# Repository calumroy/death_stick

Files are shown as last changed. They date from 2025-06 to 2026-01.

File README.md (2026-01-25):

# Death Stick

A fun death stick.

## Button Controls

Three speed buttons (active LOW, active while held):
- **SLOW** (GP2): 20A - Low power
- **MEDIUM** (GP3): 40A - Normal cruising  
- **FAST** (GP4): 70A - Full power (ramps up over 1 second)

Release all buttons to stop.

**Emergency Stop:** Hold all 3 buttons for 2 seconds. Current cuts immediately when all buttons are pressed.

**Exit Emergency Stop:** Press and hold each button in sequence (SLOW → MEDIUM → FAST), holding each for 500ms. If multiple buttons are pressed simultaneously, the sequence resets.

## Software 

The controller is an [ESP32-S3-LCD-1.47B](https://www.waveshare.com/wiki/ESP32-S3-LCD-1.47B) board.

Building and flashing the software is done using the containerized ESP-IDF build (Podman).

### Containerized ESP-IDF build (Podman)

Build and flash ESP-IDF projects in a container with access to `/dev/ttyACM0`.

Prereqs: Podman installed; user can access serial devices (often group `dialout`).

1) Initialize ESP-IDF submodule

```bash
git submodule update --init --recursive software/esp_idf
```

2) Build image

```bash
bash scripts/podman-build.sh
```

3) Run container (maps repo, caches tools, exposes `/dev/ttyACM0`)

Check that once the device is plugged in, the device is recognized by the host and is on the `/dev/ttyACM0` path.
If it comes up as something else, you can try to run the container with a different device:

```bash
bash scripts/podman-run.sh
```

Use another device:

```bash
TTY_DEVICE=/dev/ttyUSB1 bash scripts/podman-run.sh
```

Inside the container (ESP-IDF is already exported by entrypoint):

```bash
idf.py --version
idf.py set-target esp32s3
cd ./software/src/stick_controller
idf.py build
idf.py -p /dev/ttyACM0 flash monitor
```c
Quit the serial monitor by typing Ctrl-]
--- Quit: Ctrl+] | Menu: Ctrl+T | Help: Ctrl+T followed by Ctrl+H

Reattach to a running container:

```bash
bash scripts/podman-exec.sh bash
```

Troubleshooting:
- If serial permissions fail, ensure the host user is in `dialout` and the device exists. You can try `TTY_DEVICE=/dev/ttyACM0`.
- Tools cache persists in `.espressif`. Delete it to force re-install.

- If you power cycle the ESP or disconnct the USB and reconnct the podman container will need to be restarted otherwise it won't get permission to use the device serial port anymore.

## Flipsky Uart settings

App Settings → UART
    Baud rate: 115200
    UART Mode: UART
App to Use: UART

We use Uart0 to communicate from the ESP32 to the Flipsky ESC.

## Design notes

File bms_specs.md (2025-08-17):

## BMS Specifications

From here: 
https://flipsky.net/collections/bms/products/bms-8s-14s-lifepo4-li-ion

Charging current: <60A
Discharge current: < 150A
Internal resistance: ≤15mΩ
Charging voltage: The number of Li-ion battery in series connection X 4.2V
Wiring: Different Port

Detection voltage: 4.25±0.025V
Detection delay: 1000±500MS
Release voltage: 4.15±0.05V

Detection voltage: 2.75±0.1V
Detection delay: 1000±500MS
Release voltage: 3.0±0.1V

Detection voltage: 4.15±0.025V
Detection delay: 100±50MS
Balance current: 42±5MA

Detection voltage: 50±15MV
Detection delay: 1000±500MS
Current protection: 300±50A 450±50A 600±60A

Trigger condition: external short circuit
Detection delay: 300us
Release condition: disconnect the load

Charge and discharge over-temperature protection: 55℃
Charge and discharge high temperature release temperature: 75℃
Release condition: During normal working temperature

Working power consumption: <35UA
Over-discharge power consumption (Sleeping State): <10UA
Operating temperature range: -30°~+80°C

Overcharge protection
Over discharge protection
Over current protection
Balanced protection
Temperature control protection
Applicable for 8-14S battery

Size: 121*50*12.8mm
Net weight: 244g
Weight: 331.5g

1x PCBA board
1x HY2.0 single head 15P line

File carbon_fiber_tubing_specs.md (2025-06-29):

# Carbon Fiber Tubing Specs

Form here
https://enhancedcomposites.com.au/product/carbon-fibre-roll-wrap-tube-60mm-x-56mm-x-2360/

## Specs

Carbon Fibre Roll Wrap Tube – 60 x 56 x 2360 mm

$517.00 incl. GST

Length: 2360 mm
Outside Diameter (OD): 60 mm
Inside Diameter (ID): 56 mm
Wall Thickness: 2 mm

Colour: 2×2 twill carbon fibre weave finish
Type: Roll wrap 100% carbon fibre
Appearance: Glossy
Resin Matrix: Epoxy

## Description

Enhanced Composites carbon fibre roll wrap tube uses high strength unidirectional carbon fibre running length-ways down the tube for stiffness and at 90° around the tube to provide hoop strength and resilience to crush, burst and torsional loads. In addition to this high strength uni core, our tubes are finished with a classic final layer of 2×2 twill weave carbon fibre and UV-stable clear high-gloss finish. The end result is a carbon fibre tube ideally suited for use in applications where it will be seen.

The tube has an outer diameter (OD) of 60 mm and an inner diameter (ID) of 56 mm.
How to Cut and Shape

They can be cut with a fine band saw, hacksaw, or dremel tool. Enhanced Composites roll wrap carbon fibre tubes are manufactured using an epoxy matrix; therefore they will easily bond with other epoxy resins.
Typical Uses

Roll-wrapped tubes are better for applications where the tube may be subject to a variety of forces including bend, twist and crush. These light 10 mm tubes are suitable for demanding engineering applications including scale aircraft, gliders, helicopter U.A.V.’s, lightweight frames or structures, tubular vessels, poles, column supports or any construction that requires strength, rigidity and lightness yet appearance is also important. They are equally suited to other precision applications like robotics and automation.

Tubes made with epoxy resin systems have virtually zero water absorption, making them suitable for marine-based use than lower-quality tubing made with vinylester or polyester resin systems.

Discounts are available for larger quantities

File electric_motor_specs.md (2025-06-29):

# Electric Motor Specifications

options

## Flipsky 65150 Motor 160KV 3000W IP68 BLDC Motor / ESC 2-in-1 Combo For Surfing Boat Underwater Thruster |Hydro | Efoil 
In built ESC (motor controller)
https://flipsky.net/collections/waterproof-motor/products/65150-motor-160kv-3000w-ip68-bldc-motor-esc-2-in-1-combo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

Flipsky 65150 Motor 160KV 3000W IP68 BLDC Motor / ESC 2-in-1 Combo For Surfing Boat Underwater Thruster |Hydro | Efoil 

    Size: ∅ 65*150mm
    KV:160KV
    Voltage range: 4-13S
    Rated current: 30A;Maximum current:70A
    Insulation current:AC500v/1ma/3s
    Rated power:1500W;Maximum power:3000W
    Rated torque:2.3N.m;Maximum torque 4.5N.m
    Internal structure:12N/10p
    ESC drive mode:PPM
    Communication port: USB
    ESC driver firmware:5.2 vesc tool 3.00
    ESC support mode: BLDC/FOC
    Shaft specifications ∅ 12-0.005/-0.01
    Power cable: 2*12AWG(∅ 4.5mm*140)
    Power plug: XT90 male
    Weight:2.0kg

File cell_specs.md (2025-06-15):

## Specification for NMC cell
https://www.alibaba.com/product-detail/46160-NMC-Cylindrical-Cell-Rechargeable-3_1600482704719.html

Battery type
3.7V NCM Lithium Cylindrical Battery
Capacity
Max. 32Ah
Min. 31Ah
Nominal Voltage
3.7V
Max Charge Voltage
4.2V
Discharge Cut-off Voltage
2.7V
Internal Resistance
≤1mΩ
Weight
680±10g
Size
46*167(mm)
Cycle Life
>1500 times (80% of initial capacity at 2C rate, IEC Standard)
Charging Current
.Standard Charging: 62A
.Max. Charging: 93A
Disharging Current
.Max discharge current : 124A(4C)
.Max. Peak Discharging : 310A(10C)
Storage Temperature
· ≤1month: -10–45℃
· ≤3month: 0–30℃
· ≤6month: 20±5℃
Monthly self-discharge rate
≤2.5% month
Charge Temperature
0°C ~ 45°C
Discharge Temperature
-20°C ~ 60°C
Terminal
M6 Studs
Charge Mode

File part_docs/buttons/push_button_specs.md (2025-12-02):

This button is a momentary button switch(Jog switch). It means that the power is only applied when the button is pressed.Once the hand is released, the button switch is automatically reset and the power is off.
The key stroke of the product is ultra-short, the volume is ultra-thin, and the rated current is 1A

Manufacture VaneAims

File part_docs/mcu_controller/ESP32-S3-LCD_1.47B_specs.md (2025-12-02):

## ESP32-S3-LCD-1.47B

See the Waveshare wiki for details: [ESP32-S3-LCD-1.47B](https://www.waveshare.com/wiki/ESP32-S3-LCD-1.47B)

**Important:** Do not remove the screen when soldering the header pins. Tilt the iron and solder directly.

### Introduction

ESP32-S3-LCD-1.47B is a microcontroller development board with 2.4GHz Wi‑Fi and Bluetooth BLE 5. It integrates large‑capacity Flash and PSRAM and includes a 1.47" LCD capable of smoothly running GUI frameworks such as LVGL. With rich peripheral interfaces, it suits rapid HMI development and other ESP32‑S3 applications.

### Features

- Equipped with high‑performance Xtensa 32‑bit LX7 dual‑core processor, up to 240MHz
- 2.4GHz Wi‑Fi (802.11 b/g/n) and Bluetooth 5 (BLE), onboard antenna
- Built‑in 512KB SRAM, 384KB ROM, 8MB PSRAM, and 16MB Flash
- Onboard 1.47" LCD, 172×320 resolution, 262K color
- Adapts most GPIOs; integrates full‑speed USB serial port
- Onboard QMI8658 6‑axis IMU (3‑axis accelerometer + 3‑axis gyroscope)
- Onboard RGB light bead with acrylic light guide
- Onboard TF card slot for external storage
- Battery charging management module (battery connector at pin header area)
- Flexible clock and multiple power modes for low‑power scenarios

### Onboard Resources

Board overview

1. ESP32‑S3R8 — dual‑core processor, up to 240MHz  
2. 16MB Flash  
3. RGB light bead — works with onboard acrylic for lighting effects  
4. ME6217C33M5G — LDO regulator, up to 800mA output  
5. QMI8658 — six‑axis gyro accelerometer  
6. Charging management circuit  
7. Patch ceramic antenna  
8. Battery header — 3.7V Li‑ion/Li‑Po, supports charge and discharge  
9. TF card slot  
10. RESET button  
11. BOOT button  
12. Type‑C interface — power, USB communication, firmware download

### Pinouts

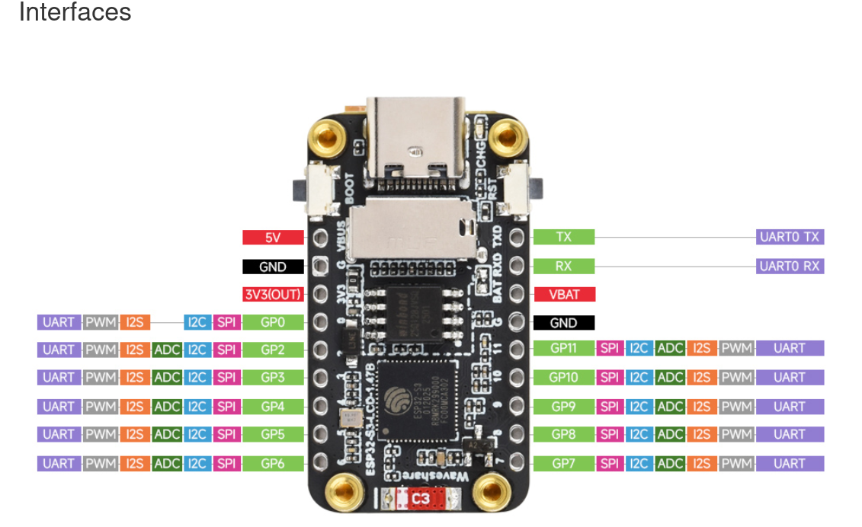
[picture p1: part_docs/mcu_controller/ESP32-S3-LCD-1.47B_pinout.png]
Pinouts


**Left-Side Pins**  

| Pin Label | Functions |
|---|---|
| **5V** | 5V Power Input |
| **GND** | Ground |
| **3V3 (OUT)** | 3.3V Output |
| **GP0** | UART, PWM, I2S, I2C, SPI |
| **GP2** | UART, PWM, I2S, ADC, I2C, SPI |
| **GP3** | UART, PWM, I2S, ADC, I2C, SPI |
| **GP4** | UART, PWM, I2S, ADC, I2C, SPI |
| **GP5** | UART, PWM, I2S, ADC, I2C, SPI |
| **GP6** | UART, PWM, I2S, ADC, I2C, SPI |

**Right-Side Pins**  

| Pin Label | Functions |
|---|---|
| **TX** | UART0 TX |
| **RX** | UART0 RX |
| **VBAT** | Battery Input |
| **GND** | Ground |
| **GP11** | SPI, I2C, ADC, I2S, PWM, UART |
| **GP10** | SPI, I2C, ADC, I2S, PWM, UART |
| **GP9**  | SPI, I2C, ADC, I2S, PWM, UART |
| **GP8**  | SPI, I2C, ADC, I2S, PWM, UART |
| **GP7**  | SPI, I2C, ADC, I2S, PWM, UART |

LCD (ST7789 controller)

| Signal | ESP32‑S3 GPIO |
|---|---|
| MOSI | GPIO45 |
| SCLK | GPIO40 |
| LCD_CS | GPIO42 |
| LCD_DC | GPIO41 |
| LCD_RST | GPIO39 |
| LCD_BL | GPIO46 |

RGB light bead

| Signal | ESP32‑S3 GPIO |
|---|---|
| RGB_Control | GPIO38 |

TF Card

| Signal | ESP32‑S3 GPIO |
|---|---|
| SD_CMD | GPIO15 |
| SD_SCK | GPIO14 |
| SD_D0  | GPIO16 |
| SD_D1  | GPIO18 |
| SD_D2  | GPIO17 |
| SD_D3  | GPIO21 |

### Specifications

| Item | Parameter |
|---|---|
| Interface | USB Type‑C |
| Controller chip | ESP32‑S3 |
| LCD type | TFT |
| LCD controller chip | ST7789 (display) |
| Onboard devices | RGB light bead |
| | TF card slot |
| | QMI8658 6‑axis IMU |
| | Charging management IC |

**Important:** Do not remove the screen when soldering the header pins. Tilt the iron and solder directly.

### Usage Instructions

ESP32‑S3‑LCD‑1.47B currently provides two development tools/frameworks: Arduino IDE and ESP‑IDF. Choose based on your project needs and personal preference.

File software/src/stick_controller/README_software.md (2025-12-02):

## Death Stick Controller Software

ESP32-S3-LCD-1.47B based motor controller with VESC UART communication.

### Features

- **VESC UART Communication**: Communicates with Flipsky VESC motor controller at 115200 baud
- **Three Speed Levels**: SLOW, MEDIUM, FAST buttons to control motor current
- **LCD Telemetry Display**: Shows voltage, current, RPM, temperature, and fault status
- **Emergency Stop**: Long-press any button to immediately stop the motor

### Hardware Connections

#### VESC UART (UART0)
| ESP32 Pin | VESC Wire | Function |
|---|---|---|
| TX (GPIO43) | Yellow | VESC RX |
| RX (GPIO44) | White | VESC TX |
| 5V | Red | Power |
| GND | Black | Ground |

#### Speed Control Buttons (Active LOW with internal pull-ups)
| ESP32 Pin | Button | Function |
|---|---|---|
| GP2 | SW1 | SLOW speed |
| GP3 | SW2 | MEDIUM speed |
| GP4 | SW3 | FAST speed |
| GND | All switches | Common ground |

### Current Settings

This project shows a background image behind the two toggle images using an LVGL image compiled into the firmware as a C array.

What’s in the code
- `main/images/screenshot1.c` defines a `const lv_img_dsc_t screenshot1` with RGB565 pixels (stored in flash).
- `main/main.c` creates an LVGL image object and sets that descriptor as the source:
  - `lv_img_set_src(bg_img_obj, &screenshot1);`
  - It’s aligned top-left, under the two foreground images.
- Build is wired in `main/CMakeLists.txt` by listing `images/screenshot1.c` among the component sources.

Replace the background (recommended)
1) Prepare your image
- Target screen size: 172x320 (portrait) for the ST7789 panel.
- Use the LVGL Image Converter: [LVGL Image Converter](https://lvgl.io/tools/imageconverter)
- Settings:
  - Color format: RGB565
  - Output: C array
  - Dithering/Compression: Off
  - Variable name: `screenshot1` (to avoid any code changes)

Inside the ESP-IDF container:

```bash
cd /workspace/software/src/stick_controller
idf.py fullclean
idf.py build
idf.py -p ${TTY_DEVICE:-/dev/ttyACM0} flash monitor
```

### Usage

1. **Power on** - The LCD will show "VESC: Connecting..." until communication is established
2. **Select speed** - Press GP2 (SLOW), GP3 (MEDIUM), or GP4 (FAST) to set motor current
3. **Toggle off** - Press the same button again to stop the motor
4. **Emergency stop** - Long-press any button to immediately stop

### LCD Display Information

- **SPEED**: Current speed setting (OFF/SLOW/MEDIUM/FAST)
- **VOLT**: Battery voltage from VESC
- **CMD**: Commanded current (what you requested)
- **MOTOR**: Actual motor current (what's flowing)
- **RPM**: Motor RPM
- **TEMP**: MOSFET temperature
- **VESC**: Connection status or fault code

### File Structure

```
main/
├── main.c                    # Main application
├── Button_Driver/
│   ├── Button_Driver.c/h     # Internal BOOT button
│   ├── Speed_Buttons.c/h     # External speed buttons (GP2,GP3,GP4)
│   └── multi_button.c/h      # Button debounce library
├── VESC_Driver/
│   └── vesc_uart.c/h         # VESC UART communication driver
├── LCD_Driver/
│   └── ST7789.c/h            # LCD driver
├── LVGL_Driver/
│   └── LVGL_Driver.c/h       # LVGL graphics driver
└── images/
    └── *.c                   # Image assets
```

### VESC Configuration

The VESC must be configured for UART communication:

1. Open VESC Tool
2. Go to **App Settings → UART**
3. Set **Baud rate**: 115200
4. Set **UART Mode**: UART
5. Go to **App Settings → General**
6. Set **App to Use**: UART

### Troubleshooting

- **"VESC: No Connection"** - Check UART wiring (TX→RX crossover), verify VESC is powered and configured for UART mode
- **Motor doesn't respond** - Verify current limits in VESC Tool, check fault codes on display
- **Buttons not working** - Verify GP2/GP3/GP4 are connected to buttons that pull to GND when pressed
- **Display garbled** - May need to clean build: `idf.py fullclean && idf.py build`

### Safety Notes

⚠️ **CAUTION**: This controls a potentially dangerous motor. Always:
- Test with motor disconnected first
- Start with low current values
- Have emergency stop ready (long-press any button)
- Never leave unattended while powered

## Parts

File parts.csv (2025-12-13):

Part | Model | Vendor Part no | Description | Quantity Required | Quantity Ordered | Cost $(of ordered quantity) | Cost $(of required quantity) | Currency | Vendor Supplier | Order Status | date ordered | URL Link
Threaded Rod |  | 175-7001 | Zinc Plated Mild Steel Threaded Rod M6 20mm | 11 | 1 bag of 50 | 26.40 | 5.80 | AUD | RS Components | Ordered | 10/06/25 | https://au.rs-online.com/web/p/threaded-rods/1757001
spring washer |  | 175-7002 | Zinc Plated Mild Steel Spring Washer M6 | 11 | 1 bag of 100 | 7.22 | 0.79 | RS Components | Ordered | 10/06/25 |  | https://au.rs-online.com/web/p/washers/2310693
Cable Gland | 50.112/EMV/R | 2291-50.112/EMV/R-ND | CABLE GLND 5-13MM 1/2 NPT BRASS | 6 | 6 | 35.88 | 35.88 | USD | DigiKey | Ordered |  | https://www.digikey.com.au/en/products/detail/jacob-gmbh/50-112-EMV-R/11674819
Cable Gland | NGM Series | 8829947 | HellermannTyton NGM Series Grey Nylon Cable Gland M12 Thread 3-6.5mm IP68 10 | 1 | 10 | 15.10 | 15.10 | AUD | RS Components | Ordered | 14/07/25 | https://au.rs-online.com/web/p/cable-glands/8829947
Heatset Insert | 4256 | 1528-4256-ND | BRASS HEATSET INSRT M3X3M 1=50PC | 50 | 1 bag of 50 | 5.95 | 5.95 | USD | DigiKey | Ordered |  | https://www.digikey.com.au/en/products/detail/adafruit-industries-llc/4256/10244655
PETG Filament | PETG175N1 | 4370-PETG175N1-ND | ESUN PETG (1.75MM 1000G)NATURE | 1 | 1 | 21.09 | 21.09 | USD | DigiKey | Ordered |  | https://www.digikey.com.au/en/products/detail/esun/PETG175N1/16734901
ABS+ Filament | ABS+175B1 | 4370-ABS+175B1-ND | ESUN ABS (1.75MM 1000G)BLACK | 1 | 1 | 21.09 | 21.09 | USD | DigiKey | Ordered |  | https://www.digikey.com.au/en/products/detail/esun/ABS-175B1/16583788
Wireless Remote VX3 |  |  | Flipsky 2.4G Wireless Module Waterproof Remote VX3 Pro controller for Efoil/ESurf/ESK8 | 1 | 1 | 110.00 | 110.00 | USD | Flipsky | Ordered | 06/07/25 | https://flipsky.net/products/flipsky-vx3-waterproof-remote-controller
Flipsky BMS |  |  | Flipsky BMS 8S-14S LiFePO4/Li-ion 24V/36V/48V Battery Pack Protection 150A for ESK8/Electric Scooter | 1 | 1 | 45.00 | 45.00 | USD | Flipsky | Ordered | 06/07/25 | https://flipsky.net/collections/bms/products/bms-8s-14s-lifepo4-li-ion
Flipsky 65150 Motor Combo | FS078 |  | Flipsky 65150 Motor 160KV 3000W IP68 BLDC Motor / ESC 2-in-1 Combo w/ prop PPM&UART 160KV | 1 | 1 | 345.60 | 345.60 | USD | Flipsky | Ordered | 06/07/25 | https://flipsky.net/collections/waterproof-motor/products/65150-motor-160kv-3000w-ip68-bldc-motor-esc-2-in-1-combo
O-Ring | RS PRO | 196-4904 | RS PRO Nitrile Rubber O-Ring 40mm Bore 44mm Outer Diameter |  | 1 bag of 50 | 20.32 | 0.40 | AUD | RS Components |  |  | https://au.rs-online.com/web/p/gaskets-o-rings/1964904
Polycarbonate Sheet | Aliexpress |  | 4mm Clear Polycarbonate Sheet 200x300mm |  | 1 | 25.79 | 25.79 | AUD |  | Ordered |  | https://www.aliexpress.com/item/1005008523118509.html
Push Button Switch | Aliexpress |  | Ultra Short Push Button Switch Waterproof 16mm 3-6v Blue LED Black Shell Momentary Self-reset | 3 | 6 | 38.28 | 19.14 | AUD | AliExpress | Ordered |  | https://www.aliexpress.com/item/1005005810452249.html
Self-Adhesive Sponge | Aliexpress |  | Self-Adhesive Sponge |  |  | 35.66 | 35.66 | CNY | AliExpress | Ordered |  | https://www.aliexpress.com/item/1005006761972394.html
Electrical Insulating Tape | Aliexpress |  | Electrical Insulating Tape Heat Resistant |  |  | 38.39 | 38.39 | CNY | AliExpress | Ordered |  | https://www.aliexpress.com/item/1005009717589369.html
O-Ring | RS PRO | 196-5062 | RS PRO Nitrile Rubber O-Ring 58mm Bore 64mm Outer Diameter |  | 1 | 16.89 | 16.89 | AUD | RS Components | Ordered | 31/08/25 | https://au.rs-online.com/web/p/gaskets-o-rings/1965062
ESP32-S3 Dev Board | Waveshare |  | Waveshare ESP32-S3 1.47-inch LCD Screen Dev Board WiFi Bluetooth RGB 172x320 Dual Core |  | 1 | 145.05 | 145.05 | CNY | AliExpress | Ordered | 13/09/25 | https://www.aliexpress.com/item/1005009453213461.html
DC-DC Buck Module | Mini Buck 2A |  | DC-DC Buck Module 60V/48V/36V/24V to 3.3V Output Car Power Converter 2A |  | 1 | 33.45 | 33.45 | CNY | AliExpress | Ordered | 13/09/25 | https://www.aliexpress.com/item/1005008564266624.html
Cable |  | W4216A | CABLE HIGH CURR. 90A RED | 2.0 | 2 | 16.4 | 16.4 | AUD | Altronics | Ordered | 14/09/25 | https://www.altronics.com.au/p/w4216a-119-0.30-90a-red-power-cable/
Cable |  | W4218A | CABLE HIGH CURR. 90A BLACK | 2.0 | 2 | 16.4 | 16.4 | AUD | Altronics | Ordered | 14/09/25 | https://www.altronics.com.au/p/w4218a-119-0.30-90a-black-power-cable/
Connector |  | P7825 | CON INLINE 600VDC 90A XT90 SET | 4.0 | 4 | 34.2 | 34.2 | AUD | Altronics | Ordered | 14/09/25 | https://www.altronics.com.au/p/p7825-90a-600v-xt90-style-high-current-dc-connector/
Cable |  | W4223 | 16AWG BLACK 7 CORE 10A TRAILER CABLE | 3.0 |  |  | 26.25 | AUD | Altronics |  |  | https://www.altronics.com.au/p/w4223-16-0.3-black-7-core-10a-trailer-cable/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
Fuse | Littelfuse | 226-0917 | Littelfuse 160A Grey, White Fuse Strips Car Fuse, 48V dc | 1 | 1 | 17.39 | 17.39 | AUD | RS Components |  |  | https://au.rs-online.com/web/p/car-fuses/2260917
Carbon Fibre Tube |  |  | Carbon Fibre Roll Wrap Tube – 60 × 56 × 2360 mm | 1 | 1 | 515.35 | 515.35 | AUD | Enhanced Composites | Ordered | 01/06/25 | https://enhancedcomposites.com.au
Prototyping Board | HP9570 |  | Small Breadboard Layout Prototyping Board | 1 | 1 | 6.75 | 6.75 | AUD | Jaycar | Ordered | 04/12/25 | https://www.jaycar.com.au/small-breadboard-layout-prototyping-board/p/HP9570
NPN Transistor | MPSA06 | ZT2286 | MPSA06 NPN Transistor | 6 | 6 | 1.80 | 1.80 | AUD | Jaycar | Ordered | 04/12/25 | https://www.jaycar.com.au/mpsa06-npn-transistor/p/ZT2286
Resistor | 220 Ohm 1W | RR2558 | 220 Ohm 1 Watt Carbon Film Resistors - Pack of 2 | 10 | 5 packs | 3.25 | 6.50 | AUD | Jaycar | Ordered | 04/12/25 | https://www.jaycar.com.au/220-ohm-1-watt-carbon-film-resistors-pack-of-2/p/RR2558
Resistor | 1.1k Ohm 0.5W | RR0573 | 1.1k Ohm 0.5 Watt Metal Film Resistors - Pack of 8 | 8 | 1 pack | 0.85 | 0.85 | AUD | Jaycar | Ordered | 04/12/25 | https://www.jaycar.com.au/1-1k-ohm-0-5-watt-metal-film-resistors-pack-of-8/p/RR0573

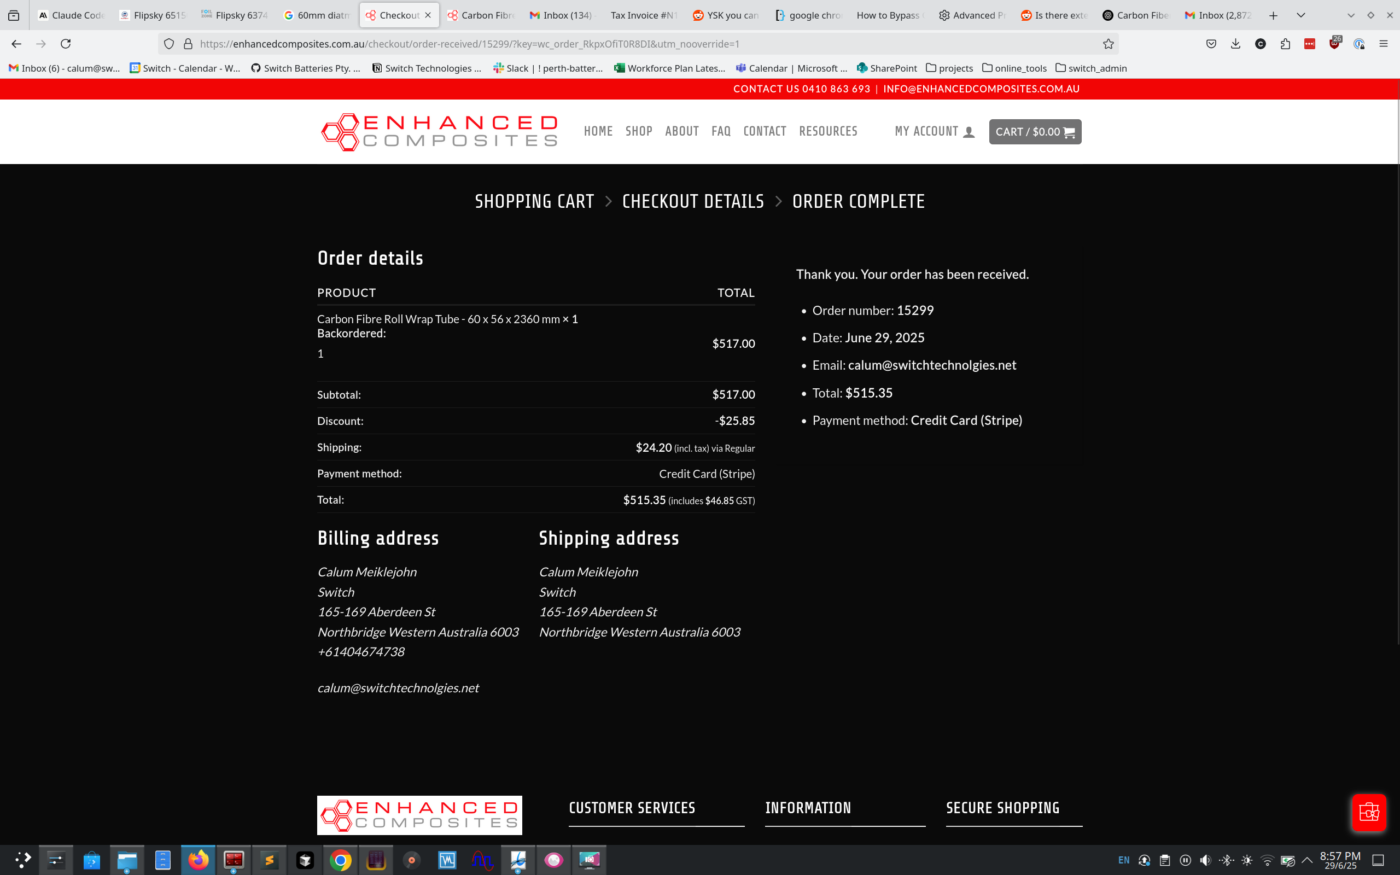
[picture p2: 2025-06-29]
orders/carbon_tubing_order_Screenshot_20250629_205705.png

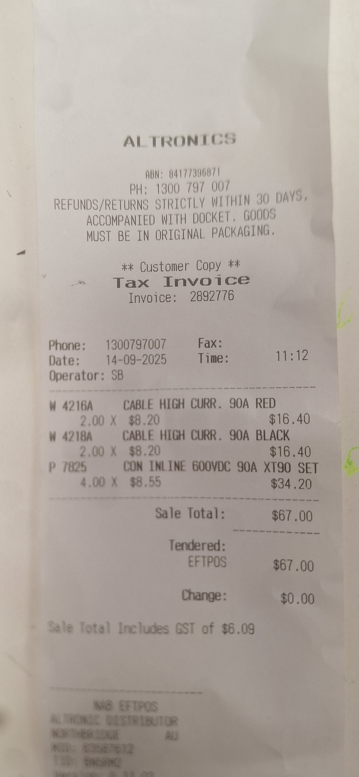
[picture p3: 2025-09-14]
orders/xt90_connectors_12awg_power_cable_altronics_receipt.jpg

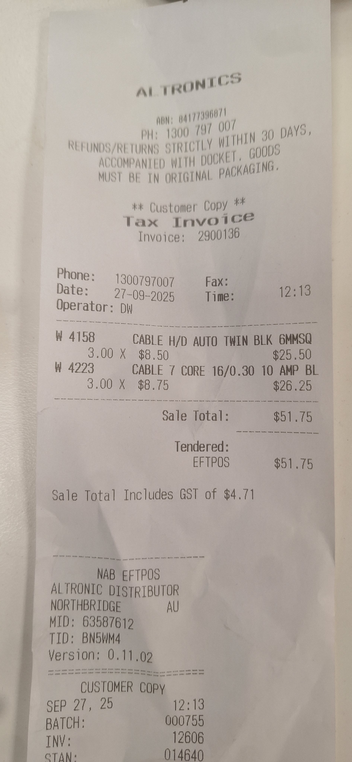
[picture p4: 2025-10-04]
orders/altronics_cable_receipt_20250927_122507.jpg

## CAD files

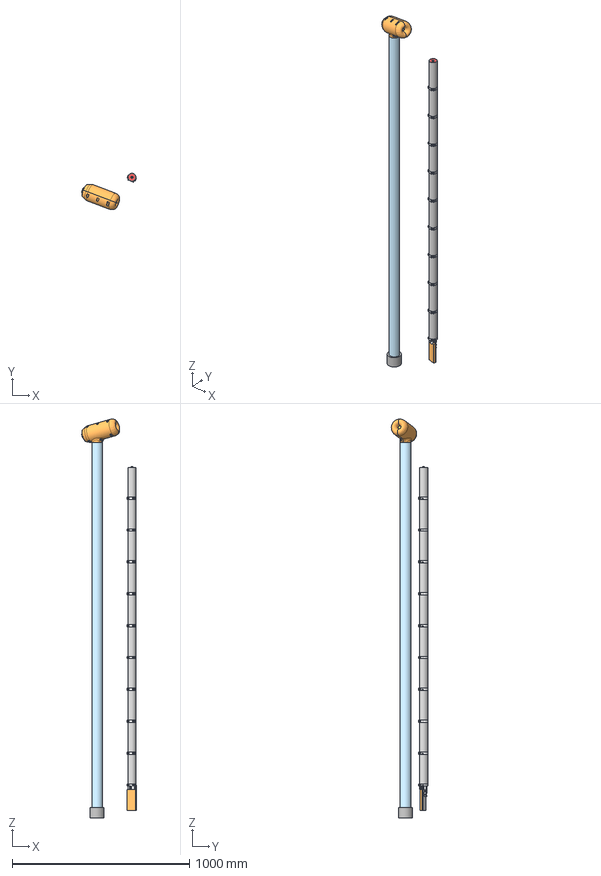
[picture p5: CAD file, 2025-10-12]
part_design_CAD/Death Stick Assembly 1.step
308.1 x 206.3 x 2253.2 mm
threader_rod x 10
M6 Ring Terminal v2 x 10
cell_spacer_pos_end
cell x 10
cell_spacer x 9
M6 Spring Washer x 10
top_tube_end_cap
motor
bms
M3 Threaded Insert (1) (2) (1) (4) x 6
motor_mount_top
body_tube
end_tube_cap
motor_mount_bottom

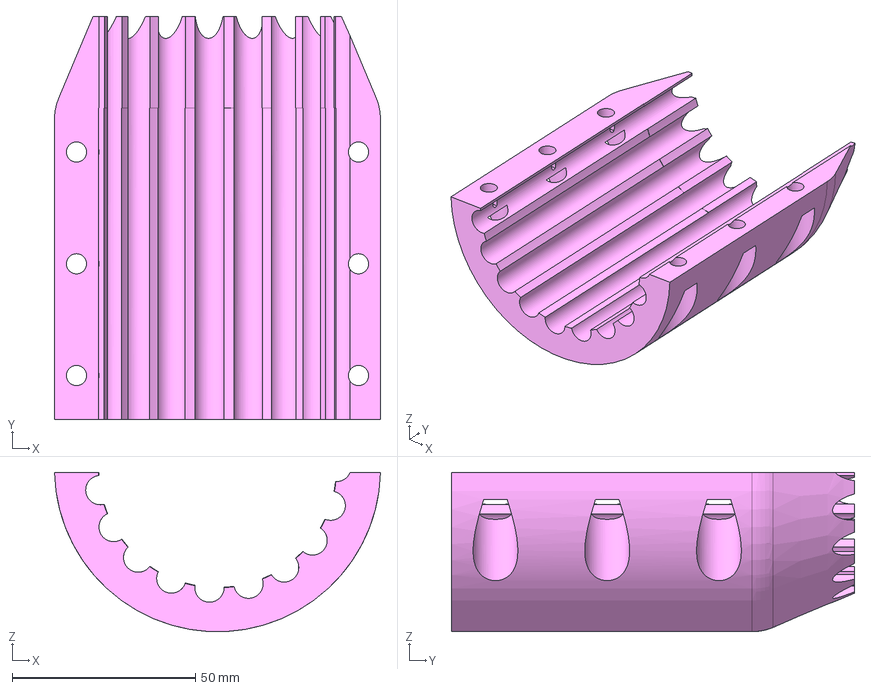
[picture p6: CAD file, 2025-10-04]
part_design_CAD/Death Stick Crotch Blender parts - Part28^Assembly 1.step
89.0 x 110.0 x 43.5 mm

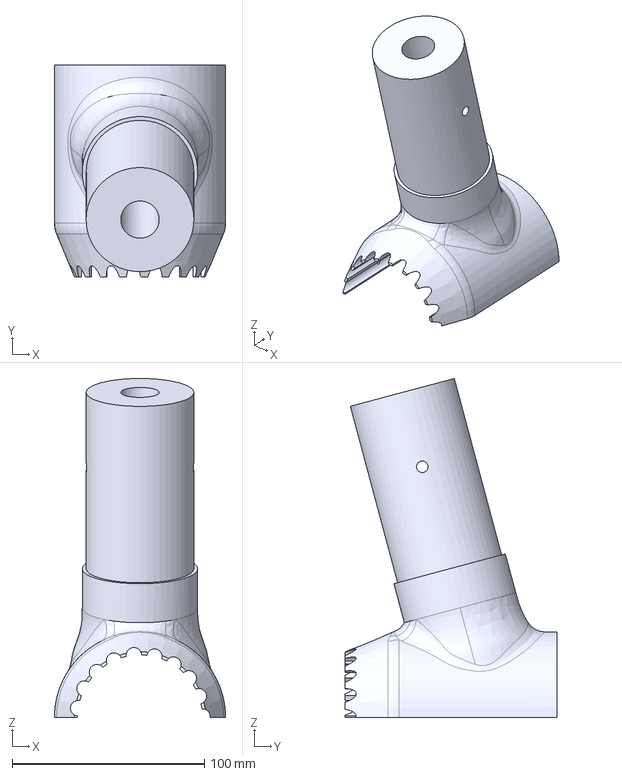
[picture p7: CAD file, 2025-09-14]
part_design_CAD/Death Stick Crotch Blender parts - Part27^Assembly 1.step
89.0 x 110.0 x 176.1 mm

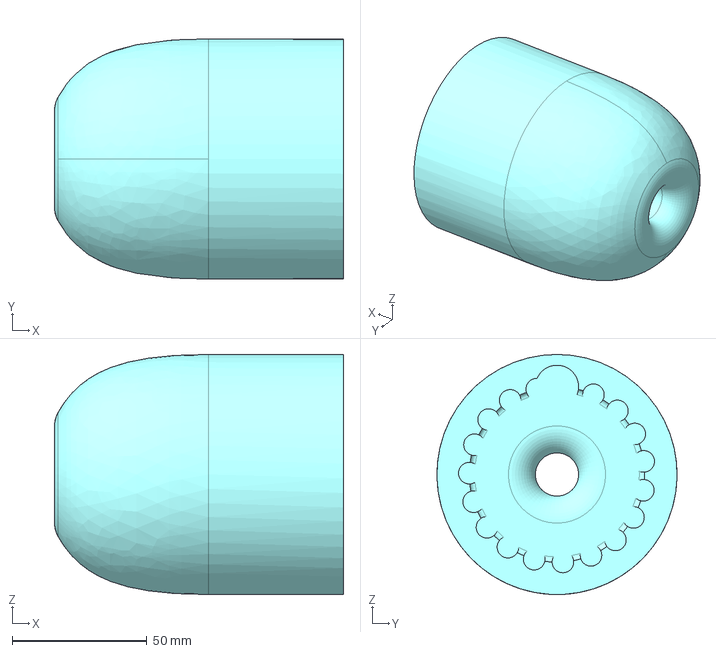
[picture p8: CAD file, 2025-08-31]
part_design_CAD/Death Stick Crotch Blender parts - Part29^Assembly 1.step
107.1 x 89.0 x 89.0 mm

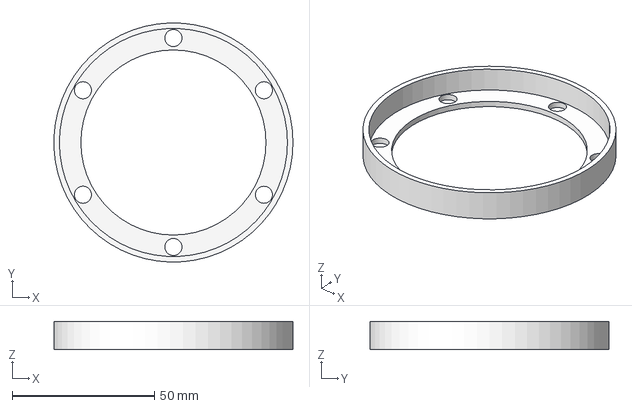
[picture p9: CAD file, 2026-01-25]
part_design_CAD/Part Studio 1 - top_end_cap.step
83.9 x 84.0 x 10.0 mm

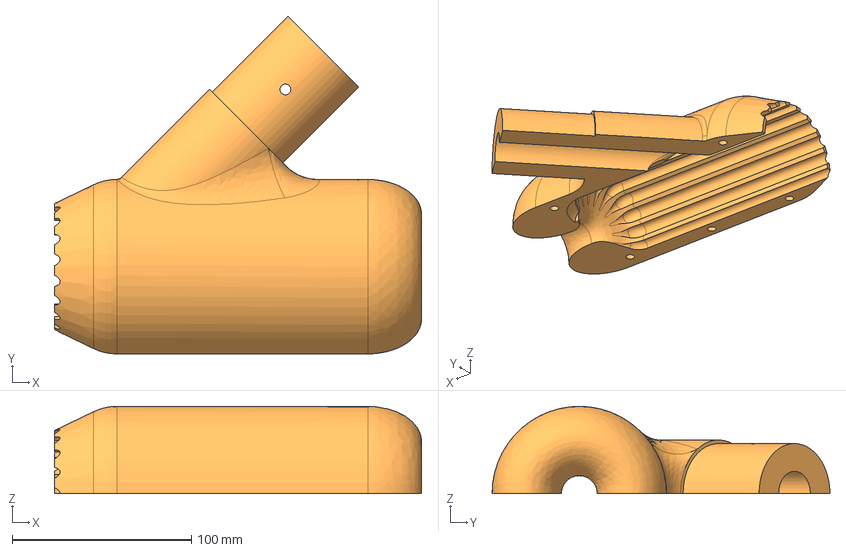
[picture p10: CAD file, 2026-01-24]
part_design_CAD/Part Studio 1 - motor_mount_bottom.step
205.0 x 188.8 x 48.8 mm

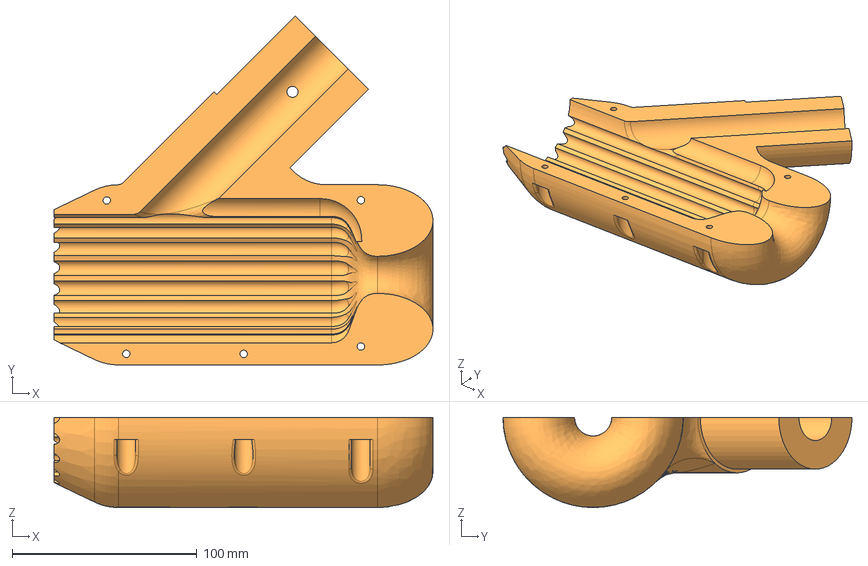
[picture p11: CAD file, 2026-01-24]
part_design_CAD/Part Studio 1 - motor_mount_top.step
205.0 x 188.8 x 48.8 mm

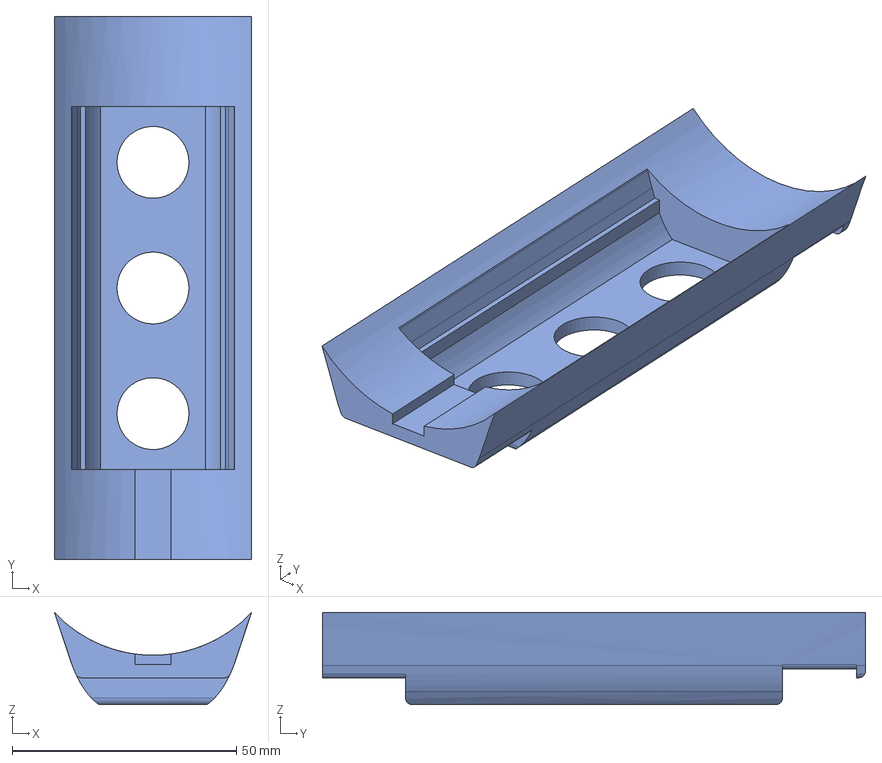
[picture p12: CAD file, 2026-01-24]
part_design_CAD/Part Studio 1 - button_holder.step
44.0 x 121.0 x 20.6 mm

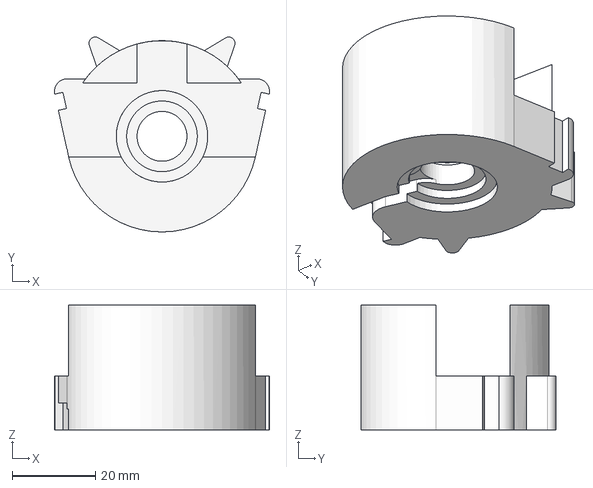
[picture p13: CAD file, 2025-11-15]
part_design_CAD/Part Studio 1 - cell_spacer_neg_end.step
51.7 x 46.9 x 30.0 mm

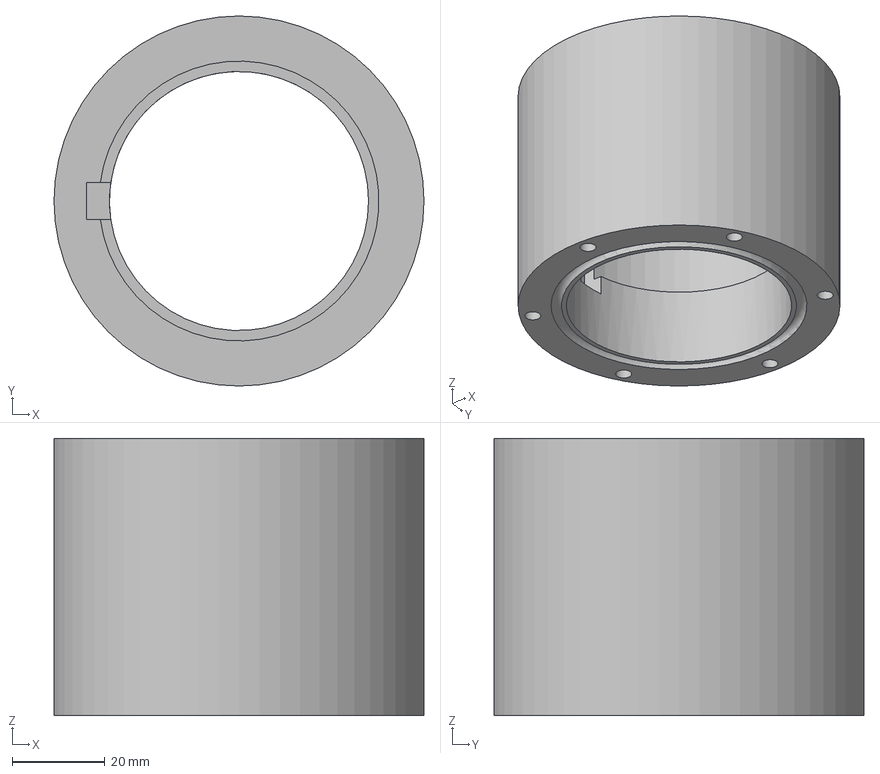
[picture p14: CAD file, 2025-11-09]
part_design_CAD/Part Studio 1 - top_tube_end_cap.step
80.0 x 80.0 x 60.0 mm

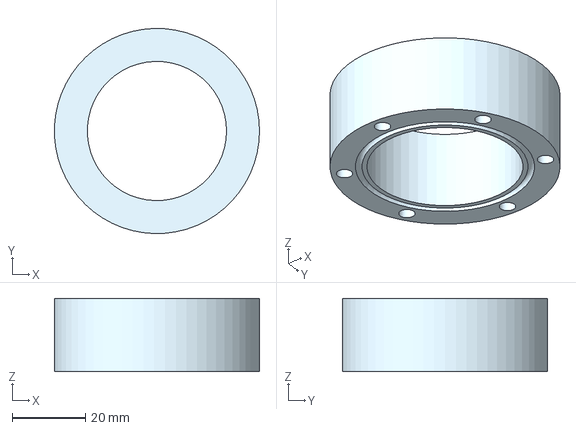
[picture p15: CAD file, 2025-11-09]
part_design_CAD/Part Studio 1 - end_tube_cap.step
56.0 x 56.0 x 20.0 mm

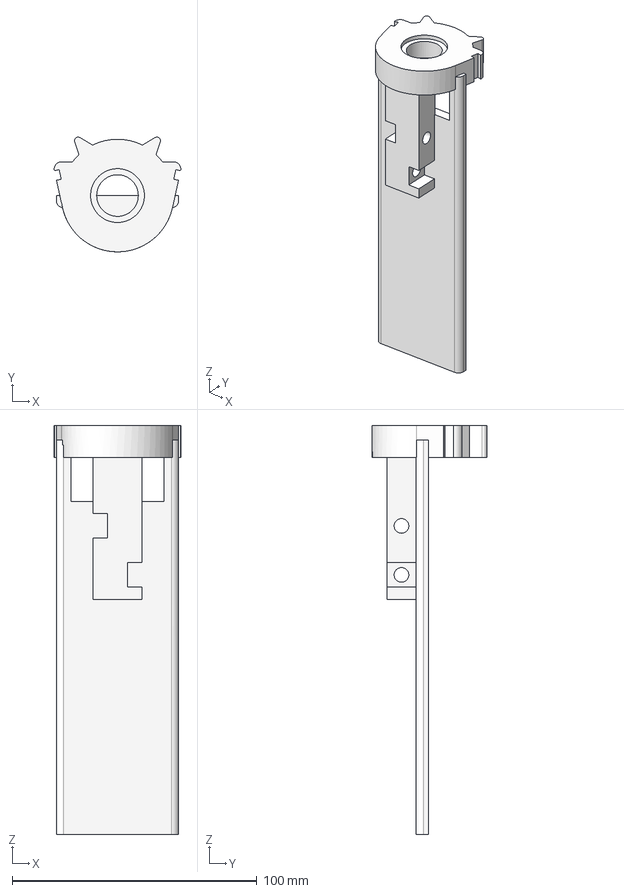
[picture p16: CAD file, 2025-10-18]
part_design_CAD/Part Studio 1 - cell_spacer_pos_end.step
51.7 x 46.9 x 167.0 mm

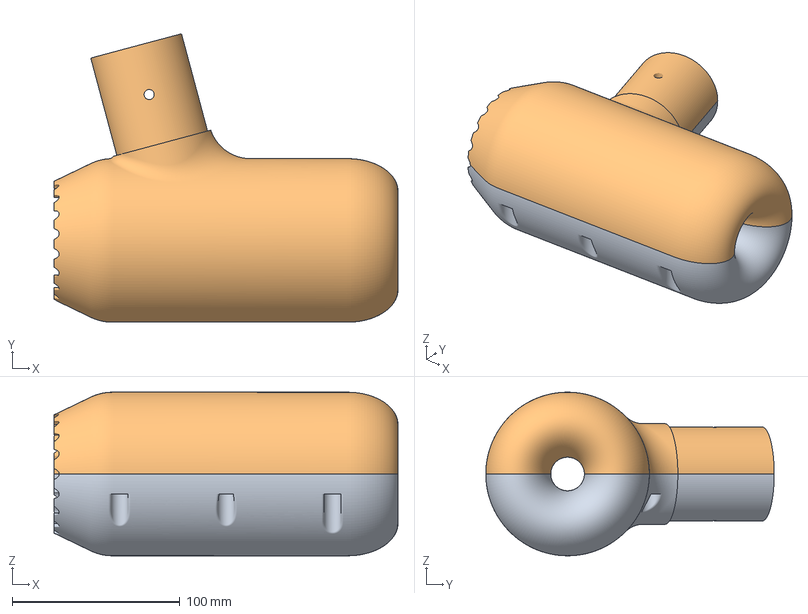
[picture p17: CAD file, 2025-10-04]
part_design_CAD/motor_holders.3mf
205.0 x 171.9 x 97.5 mm
motor_mount_top
motor_mount_bottom

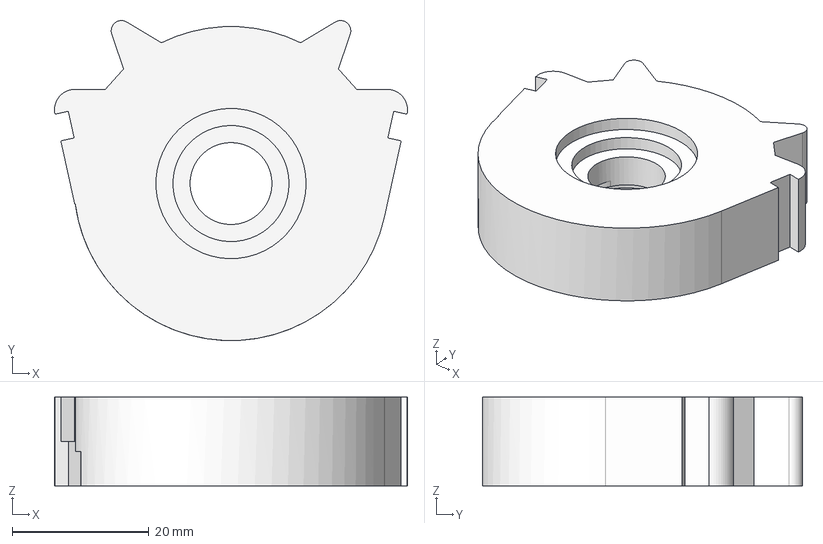
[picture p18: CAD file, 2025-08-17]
part_design_CAD/Part Studio 1 - cell_spacer.step
51.7 x 46.8 x 13.0 mm

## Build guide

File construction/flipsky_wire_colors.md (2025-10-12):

# Flipsky emotor controller wire colors

## Flipsky 65150 Motor 160KV 3000W IP68 BLDC Motor / ESC 2-in-1 Combo For Surfing Boat Underwater Thruster |Hydro | Efoil 

The uart coms uses the following wire colors:

- Yellow = original color orange to red
- blue = original color blue to yellow
- green = original color gray to white
- brown = original color purple to black

UART pin functions (original wire colors):

- Red: +5V (VCC) power out from ESC
- Yellow: RX on ESC (connect to your MCU/adapter TX)
- White: TX on ESC (connect to your MCU/adapter RX)
- Black: GND

Notes:

- Logic level is 3.3V UART; don’t drive ESC pins with 5V logic.
- Cross TX/RX when connecting to your device.

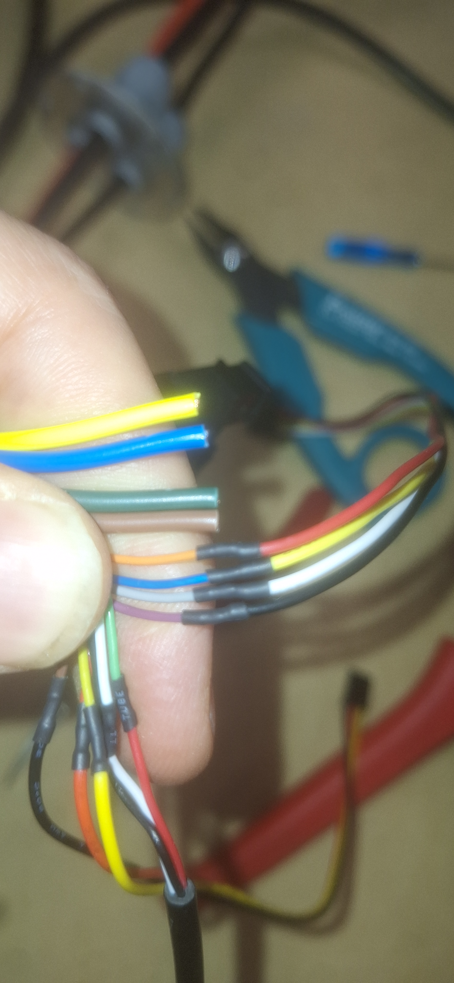
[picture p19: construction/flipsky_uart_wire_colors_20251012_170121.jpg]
Uart wire colors


The usb uses the following wire colors:

- Black: GND
- Green: D+
- White: D-

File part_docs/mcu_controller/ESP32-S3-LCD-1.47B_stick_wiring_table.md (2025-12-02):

# Wiring Table for the Stick Controller

How to wire up the ESP32-S3-LCD-1.47B to the VESC UART and the digital inputs?

VESC_UART
-Red: 5V_OUT
-Black: GND
-Yellow: TX (VESC_TX)
-White: RX (VESC_RX)
--
ESP32_S3_UART
-5V: Power_Input
-GND: Ground
-RX: UART0_RX
-TX: UART0_TX
--
Connections_UART
-Red    -> 5V
-Black  -> GND
-Yellow -> RX (ESP32_S3)
-White  -> TX (ESP32_S3)
--
ESP32_S3_DIGITAL_INPUTS
-GP2: Digital_Input_1
-GP3: Digital_Input_2
-GP4: Digital_Input_3
-3V3: Provides pull-up if needed
-GND: Common ground for all switches
--
Switch_Wiring
-SW1 -> GP2 (other side to GND)
-SW2 -> GP3 (other side to GND)
-SW3 -> GP4 (other side to GND)
--
Notes
-Configure these GPIOs as INPUT_PULLUP
-Switches pull the pin LOW when pressed
-All switches must share the ESP32 GND

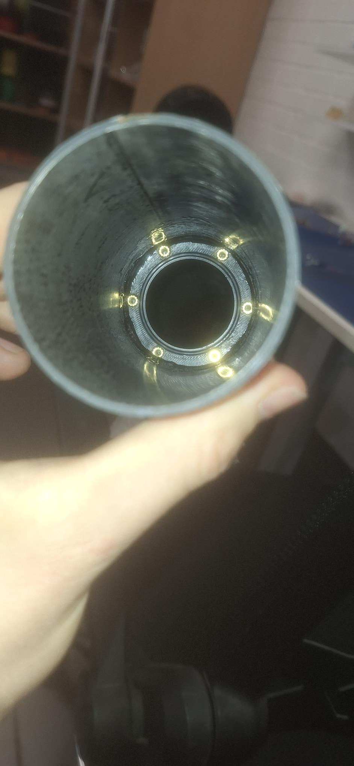
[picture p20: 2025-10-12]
construction/end_internal_seal_20251012_165258.jpg

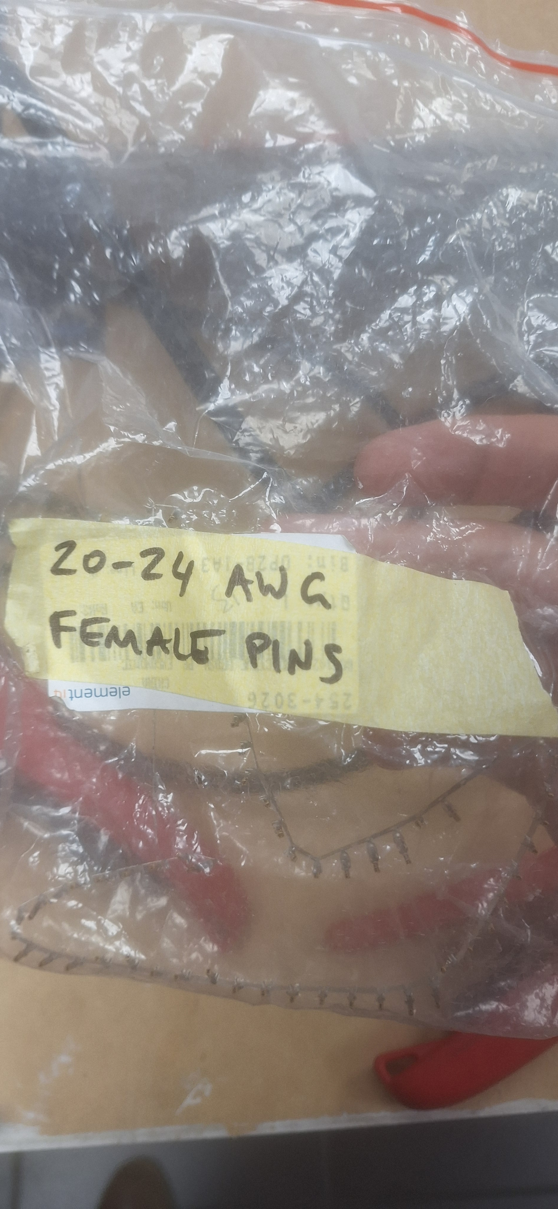
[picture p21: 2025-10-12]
construction/comms_crimp_pin_type_20251012_155932.jpg

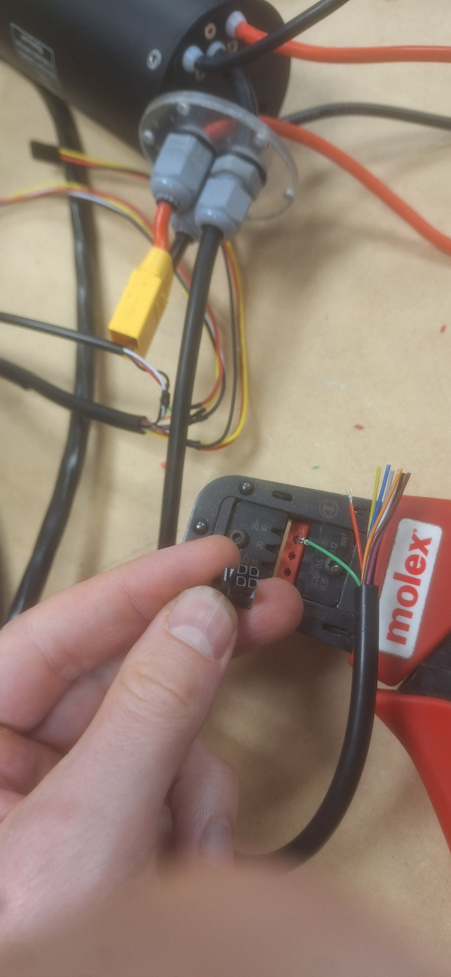
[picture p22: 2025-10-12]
construction/crimp_molex_comms_pins_for_flipsky_20251012_160224.jpg

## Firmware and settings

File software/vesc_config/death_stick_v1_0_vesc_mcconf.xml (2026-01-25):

<?xml version="1.0" encoding="UTF-8"?>
<MCConfiguration>
    <pwm_mode>1</pwm_mode>
    <comm_mode>0</comm_mode>
    <motor_type>2</motor_type>
    <sensor_mode>0</sensor_mode>
    <l_current_max>82.5898</l_current_max>
    <l_current_min>-82.5898</l_current_min>
    <l_in_current_max>99</l_in_current_max>
    <l_in_current_min>-60</l_in_current_min>
    <l_abs_current_max>150</l_abs_current_max>
    <l_min_erpm>-100000</l_min_erpm>
    <l_max_erpm>100000</l_max_erpm>
    <l_erpm_start>0.8</l_erpm_start>
    <l_max_erpm_fbrake>300</l_max_erpm_fbrake>
    <l_max_erpm_fbrake_cc>1500</l_max_erpm_fbrake_cc>
    <l_min_vin>8</l_min_vin>
    <l_max_vin>57</l_max_vin>
    <l_battery_cut_start>31</l_battery_cut_start>
    <l_battery_cut_end>28.5</l_battery_cut_end>
    <l_slow_abs_current>0</l_slow_abs_current>
    <l_temp_fet_start>85</l_temp_fet_start>
    <l_temp_fet_end>100</l_temp_fet_end>
    <l_temp_motor_start>85</l_temp_motor_start>
    <l_temp_motor_end>100</l_temp_motor_end>
    <l_temp_accel_dec>0.15</l_temp_accel_dec>
    <l_min_duty>0.005</l_min_duty>
    <l_max_duty>0.95</l_max_duty>
    <l_watt_max>1.5e+06</l_watt_max>
    <l_watt_min>-1.5e+06</l_watt_min>
    <l_current_max_scale>1</l_current_max_scale>
    <l_current_min_scale>1</l_current_min_scale>
    <l_duty_start>1</l_duty_start>
    <sl_min_erpm>150</sl_min_erpm>
    <sl_min_erpm_cycle_int_limit>1100</sl_min_erpm_cycle_int_limit>
    <sl_max_fullbreak_current_dir_change>10</sl_max_fullbreak_current_dir_change>
    <sl_cycle_int_limit>62</sl_cycle_int_limit>
    <sl_phase_advance_at_br>0.8</sl_phase_advance_at_br>
    <sl_cycle_int_rpm_br>80000</sl_cycle_int_rpm_br>
    <sl_bemf_coupling_k>600</sl_bemf_coupling_k>
    <hall_table__0>-1</hall_table__0>
    <hall_table__1>1</hall_table__1>
    <hall_table__2>3</hall_table__2>
    <hall_table__3>2</hall_table__3>
    <hall_table__4>5</hall_table__4>
    <hall_table__5>6</hall_table__5>
    <hall_table__6>4</hall_table__6>
    <hall_table__7>-1</hall_table__7>
    <hall_sl_erpm>2000</hall_sl_erpm>
    <foc_current_kp>0.0194264</foc_current_kp>
    <foc_current_ki>29.3209</foc_current_ki>
    <foc_f_sw>25000</foc_f_sw>
    <foc_dt_us>0.12</foc_dt_us>
    <foc_encoder_inverted>0</foc_encoder_inverted>
    <foc_encoder_offset>180</foc_encoder_offset>
    <foc_encoder_ratio>7</foc_encoder_ratio>
    <foc_encoder_sin_gain>1</foc_encoder_sin_gain>
    <foc_encoder_cos_gain>1</foc_encoder_cos_gain>
    <foc_encoder_sin_offset>1.65</foc_encoder_sin_offset>
    <foc_encoder_cos_offset>1.65</foc_encoder_cos_offset>
    <foc_encoder_sincos_filter_constant>0.5</foc_encoder_sincos_filter_constant>
    <foc_sensor_mode>0</foc_sensor_mode>
    <foc_pll_kp>2000</foc_pll_kp>
    <foc_pll_ki>30000</foc_pll_ki>
    <foc_motor_l>1.94264e-05</foc_motor_l>
    <foc_motor_ld_lq_diff>0</foc_motor_ld_lq_diff>
    <foc_motor_r>0.0293209</foc_motor_r>
    <foc_motor_flux_linkage>0.0104047</foc_motor_flux_linkage>
    <foc_observer_gain>9.23728e+06</foc_observer_gain>
    <foc_observer_gain_slow>0.05</foc_observer_gain_slow>
    <foc_duty_dowmramp_kp>10</foc_duty_dowmramp_kp>
    <foc_duty_dowmramp_ki>200</foc_duty_dowmramp_ki>
    <foc_openloop_rpm>700</foc_openloop_rpm>
    <foc_openloop_rpm_low>0</foc_openloop_rpm_low>
    <foc_d_gain_scale_start>0.9</foc_d_gain_scale_start>
    <foc_d_gain_scale_max_mod>0.2</foc_d_gain_scale_max_mod>
    <foc_sl_openloop_hyst>0.1</foc_sl_openloop_hyst>
    <foc_sl_openloop_time_lock>0</foc_sl_openloop_time_lock>
    <foc_sl_openloop_time_ramp>0.1</foc_sl_openloop_time_ramp>
    <foc_sl_openloop_time>0.05</foc_sl_openloop_time>
    <foc_hall_table__0>255</foc_hall_table__0>
    <foc_hall_table__1>255</foc_hall_table__1>
    <foc_hall_table__2>255</foc_hall_table__2>
    <foc_hall_table__3>255</foc_hall_table__3>
    <foc_hall_table__4>255</foc_hall_table__4>
    <foc_hall_table__5>255</foc_hall_table__5>
    <foc_hall_table__6>255</foc_hall_table__6>
    <foc_hall_table__7>255</foc_hall_table__7>
    <foc_hall_interp_erpm>500</foc_hall_interp_erpm>
    <foc_sl_erpm>4000</foc_sl_erpm>
    <foc_sample_v0_v7>0</foc_sample_v0_v7>
    <foc_sample_high_current>0</foc_sample_high_current>
    <foc_sat_comp>0</foc_sat_comp>
    <foc_temp_comp>0</foc_temp_comp>
    <foc_temp_comp_base_temp>25</foc_temp_comp_base_temp>
    <foc_current_filter_const>0.1</foc_current_filter_const>
    <foc_cc_decoupling>2</foc_cc_decoupling>
    <foc_observer_type>0</foc_observer_type>
    <foc_hfi_voltage_start>20</foc_hfi_voltage_start>
    <foc_hfi_voltage_run>4</foc_hfi_voltage_run>
    <foc_hfi_voltage_max>10</foc_hfi_voltage_max>
    <foc_sl_erpm_hfi>2000</foc_sl_erpm_hfi>
    <foc_hfi_start_samples>65</foc_hfi_start_samples>
    <foc_hfi_obs_ovr_sec>0.001</foc_hfi_obs_ovr_sec>
    <foc_hfi_samples>1</foc_hfi_samples>
    <gpd_buffer_notify_left>200</gpd_buffer_notify_left>
    <gpd_buffer_interpol>0</gpd_buffer_interpol>
    <gpd_current_filter_const>0.1</gpd_current_filter_const>
    <gpd_current_kp>0.03</gpd_current_kp>
    <gpd_current_ki>50</gpd_current_ki>
    <s_pid_kp>0.004</s_pid_kp>
    <s_pid_ki>0.004</s_pid_ki>
    <s_pid_kd>0.0001</s_pid_kd>
    <s_pid_kd_filter>0.2</s_pid_kd_filter>
    <s_pid_min_erpm>900</s_pid_min_erpm>
    <s_pid_allow_braking>1</s_pid_allow_braking>
    <s_pid_ramp_erpms_s>-1</s_pid_ramp_erpms_s>
    <p_pid_kp>0.03</p_pid_kp>
    <p_pid_ki>0</p_pid_ki>
    <p_pid_kd>0.0004</p_pid_kd>
    <p_pid_kd_filter>0.2</p_pid_kd_filter>
    <p_pid_ang_div>1</p_pid_ang_div>
    <cc_startup_boost_duty>0.01</cc_startup_boost_duty>
    <cc_min_current>0.05</cc_min_current>
    <cc_gain>0.0046</cc_gain>
    <cc_ramp_step_max>0.04</cc_ramp_step_max>
    <m_fault_stop_time_ms>500</m_fault_stop_time_ms>
    <m_duty_ramp_step>0.02</m_duty_ramp_step>
    <m_current_backoff_gain>0.5</m_current_backoff_gain>
    <m_encoder_counts>8192</m_encoder_counts>
    <m_sensor_port_mode>0</m_sensor_port_mode>
    <m_invert_direction>1</m_invert_direction>
    <m_drv8301_oc_mode>0</m_drv8301_oc_mode>
    <m_drv8301_oc_adj>16</m_drv8301_oc_adj>
    <m_bldc_f_sw_min>3000</m_bldc_f_sw_min>
    <m_bldc_f_sw_max>35000</m_bldc_f_sw_max>
    <m_dc_f_sw>25000</m_dc_f_sw>
    <m_ntc_motor_beta>3380</m_ntc_motor_beta>
    <m_out_aux_mode>0</m_out_aux_mode>
    <m_motor_temp_sens_type>0</m_motor_temp_sens_type>
    <m_ptc_motor_coeff>0.61</m_ptc_motor_coeff>
    <m_hall_extra_samples>1</m_hall_extra_samples>
    <si_motor_poles>14</si_motor_poles>
    <si_gear_ratio>1</si_gear_ratio>
    <si_wheel_diameter>0.083</si_wheel_diameter>
    <si_battery_type>0</si_battery_type>
    <si_battery_cells>10</si_battery_cells>
    <si_battery_ah>31</si_battery_ah>
    <motor_brand>Unnamed</motor_brand>
    <motor_model>Not Specified</motor_model>
    <motor_weight>0</motor_weight>
    <motor_poles>14</motor_poles>
    <motor_sensor_type>0</motor_sensor_type>
    <motor_description>&lt;!DOCTYPE HTML PUBLIC &quot;-//W3C//DTD HTML 4.0//EN&quot; &quot;http://www.w3.org/TR/REC-html40/strict.dtd&quot;&gt;
&lt;html&gt;&lt;head&gt;&lt;meta name=&quot;qrichtext&quot; content=&quot;1&quot; /&gt;&lt;style type=&quot;text/css&quot;&gt;
p, li { white-space: pre-wrap; }
&lt;/style&gt;&lt;/head&gt;&lt;body style=&quot; font-family:'Roboto'; font-size:12pt; font-weight:400; font-style:normal;&quot;&gt;
&lt;p style=&quot; margin-top:0px; margin-bottom:0px; margin-left:0px; margin-right:0px; -qt-block-indent:0; text-indent:0px;&quot;&gt;A motor description can be edited here.&lt;/p&gt;&lt;/body&gt;&lt;/html&gt;</motor_description>
    <motor_loss_torque>0.03</motor_loss_torque>
    <motor_quality_bearings>0</motor_quality_bearings>
    <motor_quality_magnets>0</motor_quality_magnets>
    <motor_quality_construction>0</motor_quality_construction>
    <motor_quality_description>&lt;!DOCTYPE HTML PUBLIC &quot;-//W3C//DTD HTML 4.0//EN&quot; &quot;http://www.w3.org/TR/REC-html40/strict.dtd&quot;&gt;
&lt;html&gt;&lt;head&gt;&lt;meta name=&quot;qrichtext&quot; content=&quot;1&quot; /&gt;&lt;style type=&quot;text/css&quot;&gt;
p, li { white-space: pre-wrap; }
&lt;/style&gt;&lt;/head&gt;&lt;body style=&quot; font-family:'Roboto'; font-size:12pt; font-weight:400; font-style:normal;&quot;&gt;
&lt;p style=&quot; margin-top:0px; margin-bottom:0px; margin-left:0px; margin-right:0px; -qt-block-indent:0; text-indent:0px;&quot;&gt;Some comments about the motor quality. Images can be added as well.&lt;/p&gt;&lt;/body&gt;&lt;/html&gt;</motor_quality_description>
    <bms.type>1</bms.type>
    <bms.t_limit_start>45</bms.t_limit_start>
    <bms.t_limit_end>65</bms.t_limit_end>
    <bms.soc_limit_start>0.05</bms.soc_limit_start>
    <bms.soc_limit_end>0</bms.soc_limit_end>
</MCConfiguration>

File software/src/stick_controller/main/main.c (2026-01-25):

/**
 * @file main.c
 * @brief Death Stick Controller - Main Application
 * 
 * Controls a VESC motor controller via UART with three speed levels
 * and displays telemetry on the built-in LCD with background image.
 * 
 * Speed Buttons (active LOW with internal pull-ups):
 *   GP2 - SLOW:   Low current
 *   GP3 - MEDIUM: Medium current
 *   GP4 - FAST:   High current
 * 
 * VESC Communication:
 *   UART0 at 115200 baud
 *   TX -> VESC RX (Yellow wire)
 *   RX -> VESC TX (White wire)
 */

#include "freertos/FreeRTOS.h"
#include "freertos/task.h"
#include "esp_log.h"
#include "esp_timer.h"
#include "lvgl.h"

#include "LCD_Driver/ST7789.h"
#include "LVGL_Driver/LVGL_Driver.h"
#include "Button_Driver/Button_Driver.h"
#include "Button_Driver/Speed_Buttons.h"
#include "VESC_Driver/vesc_uart.h"
#include <stdbool.h>
#include <stdint.h>
#include <stdio.h>
#include <string.h>

static const char *TAG = "stick_controller";

// =============================================================================
// Background Image (rotated 90° for landscape view)
// =============================================================================

// Original portrait background image (172 wide x 320 tall)
extern const lv_img_dsc_t dark_retro_sea_small;

// Rotated image buffer and descriptor
static lv_img_dsc_t bg_img_rotated;
static uint16_t bg_img_rotated_buf[EXAMPLE_LCD_H_RES * EXAMPLE_LCD_V_RES];

// Rotate image 90 degrees clockwise
static void rotate_bg_90_cw(void) {
    const lv_img_dsc_t *src = &dark_retro_sea_small;
    const uint16_t *src16 = (const uint16_t *)src->data;
    uint16_t *dst16 = bg_img_rotated_buf;
    uint16_t src_w = src->header.w;
    uint16_t src_h = src->header.h;
    uint16_t dst_w = src_h;
    
    for (uint16_t y = 0; y < src_h; y++) {
        for (uint16_t x = 0; x < src_w; x++) {
            uint32_t src_idx = (uint32_t)y * src_w + x;
            uint16_t new_x = (uint16_t)(src_h - 1 - y);
            uint16_t new_y = x;
            uint32_t dst_idx = (uint32_t)new_y * dst_w + new_x;
            dst16[dst_idx] = src16[src_idx];
        }
    }
    
    bg_img_rotated.header.always_zero = 0;
    bg_img_rotated.header.w = src_h;
    bg_img_rotated.header.h = src_w;
    bg_img_rotated.header.cf = LV_IMG_CF_TRUE_COLOR;
    bg_img_rotated.data_size = (uint32_t)src_w * src_h * 2;
    bg_img_rotated.data = (const uint8_t *)bg_img_rotated_buf;
}

// =============================================================================
// MOTOR CURRENT SETTINGS (Adjustable)
// =============================================================================

#define CURRENT_SLOW    20.0f   // Low power mode (Amps)
#define CURRENT_MEDIUM  40.0f   // Normal cruising (Amps)
#define CURRENT_FAST    70.0f   // Full power (Amps)

#define VESC_POLL_INTERVAL_MS   200
// Re-assert the current command periodically so the VESC doesn't time out or
// "forget" the last setpoint if a packet is missed.
#define VESC_CMD_INTERVAL_MS    100

// Ramp time for FAST button - current ramps from previous value to CURRENT_FAST
#define RAMP_TIME_FAST_MS       1000    // Time to ramp to FAST current (ms)

// Emergency stop settings
#define EMERGENCY_ENTER_HOLD_MS 2000    // Hold all buttons this long to enter emergency stop
#define EMERGENCY_EXIT_HOLD_MS  500     // Hold each button this long in exit sequence

// =============================================================================
// UI Elements
// =============================================================================

static lv_obj_t *bg_img_obj = NULL;
static lv_obj_t *lbl_title = NULL;
static lv_obj_t *lbl_voltage = NULL;
static lv_obj_t *lbl_current = NULL;
static lv_obj_t *lbl_amp_hours = NULL;
static lv_obj_t *lbl_rpm = NULL;
static lv_obj_t *lbl_speed_level = NULL;
static lv_obj_t *lbl_fault = NULL;
static lv_obj_t *lbl_temp = NULL;
static lv_obj_t *lbl_emergency = NULL;

static volatile speed_level_t commanded_speed = SPEED_LEVEL_OFF;
static volatile float commanded_current = 0.0f;
static vesc_data_t vesc_data = {0};
static volatile bool vesc_connected = false;
static volatile bool emergency_stop_active = false;

// =============================================================================
// UI Creation - Portrait layout with rotated background
// Screen: 172 wide x 320 tall (portrait)
// =============================================================================

static void ui_create(void) {
    // Rotate and display background image
    rotate_bg_90_cw();
    bg_img_obj = lv_img_create(lv_scr_act());
    lv_img_set_src(bg_img_obj, &bg_img_rotated);
    lv_obj_align(bg_img_obj, LV_ALIGN_TOP_LEFT, 0, 0);

    // Semi-transparent overlay for text readability
    lv_obj_t *overlay = lv_obj_create(lv_scr_act());
    lv_obj_remove_style_all(overlay);
    lv_obj_set_size(overlay, 172, 320);
    lv_obj_set_style_bg_color(overlay, lv_color_hex(0x000000), 0);
    lv_obj_set_style_bg_opa(overlay, LV_OPA_40, 0);
    lv_obj_align(overlay, LV_ALIGN_TOP_LEFT, 0, 0);

    // Styles - using larger fonts (16 for data, 18 for title/speed)
    static lv_style_t style_title;
    lv_style_init(&style_title);
    lv_style_set_text_color(&style_title, lv_color_hex(0x00FFC8));
    lv_style_set_text_font(&style_title, &lv_font_montserrat_18);

    static lv_style_t style_data;
    lv_style_init(&style_data);
    lv_style_set_text_color(&style_data, lv_color_hex(0xFFFFFF));
    lv_style_set_text_font(&style_data, &lv_font_montserrat_16);

    static lv_style_t style_speed;
    lv_style_init(&style_speed);
    lv_style_set_text_color(&style_speed, lv_color_hex(0xFFD700));
    lv_style_set_text_font(&style_speed, &lv_font_montserrat_18);

    static lv_style_t style_fault;
    lv_style_init(&style_fault);
    lv_style_set_text_color(&style_fault, lv_color_hex(0xFF4444));
    lv_style_set_text_font(&style_fault, &lv_font_montserrat_16);

    static lv_style_t style_emergency;
    lv_style_init(&style_emergency);
    lv_style_set_text_color(&style_emergency, lv_color_hex(0xFF3333));
    lv_style_set_text_font(&style_emergency, &lv_font_montserrat_18);

    // ==========================================================================
    // PORTRAIT LAYOUT (172 x 320) - Single column, vertically stacked
    // ==========================================================================
    int y = 8;
    int line_height = 26;  // Larger for bigger fonts
    int x_margin = 5;

    // Title
    lbl_title = lv_label_create(lv_scr_act());
    lv_obj_add_style(lbl_title, &style_title, 0);
    lv_label_set_text(lbl_title, "DEATH STICK");
    lv_obj_align(lbl_title, LV_ALIGN_TOP_MID, 0, y);
    y += line_height + 2;

    // Speed Level (prominent)
    lbl_speed_level = lv_label_create(lv_scr_act());
    lv_obj_add_style(lbl_speed_level, &style_speed, 0);
    lv_label_set_text(lbl_speed_level, "[ OFF ]");
    lv_obj_align(lbl_speed_level, LV_ALIGN_TOP_MID, 0, y);
    y += line_height + 8;

    // Emergency status (hidden until active)
    lbl_emergency = lv_label_create(lv_scr_act());
    lv_obj_add_style(lbl_emergency, &style_emergency, 0);
    lv_label_set_text(lbl_emergency, "");
    lv_obj_align(lbl_emergency, LV_ALIGN_TOP_MID, 0, y);
    y += line_height + 2;

    // Voltage
    lbl_voltage = lv_label_create(lv_scr_act());
    lv_obj_add_style(lbl_voltage, &style_data, 0);
    lv_label_set_text(lbl_voltage, "VOLT: --.- V");
    lv_obj_align(lbl_voltage, LV_ALIGN_TOP_LEFT, x_margin, y);
    y += line_height;

    // Current
    lbl_current = lv_label_create(lv_scr_act());
    lv_obj_add_style(lbl_current, &style_data, 0);
    lv_label_set_text(lbl_current, "AMPS: --.- A");
    lv_obj_align(lbl_current, LV_ALIGN_TOP_LEFT, x_margin, y);
    y += line_height;

    // Amp Hours
    lbl_amp_hours = lv_label_create(lv_scr_act());
    lv_obj_add_style(lbl_amp_hours, &style_data, 0);
    lv_label_set_text(lbl_amp_hours, "Ah: --.-- Ah");
    lv_obj_align(lbl_amp_hours, LV_ALIGN_TOP_LEFT, x_margin, y);
    y += line_height;

    // RPM
    lbl_rpm = lv_label_create(lv_scr_act());
    lv_obj_add_style(lbl_rpm, &style_data, 0);
    lv_label_set_text(lbl_rpm, "RPM: -----");
    lv_obj_align(lbl_rpm, LV_ALIGN_TOP_LEFT, x_margin, y);
    y += line_height;

    // Temperature
    lbl_temp = lv_label_create(lv_scr_act());
    lv_obj_add_style(lbl_temp, &style_data, 0);
    lv_label_set_text(lbl_temp, "TEMP: --.- C");
    lv_obj_align(lbl_temp, LV_ALIGN_TOP_LEFT, x_margin, y);

    // Fault Status - at bottom
    lbl_fault = lv_label_create(lv_scr_act());
    lv_obj_add_style(lbl_fault, &style_fault, 0);
    lv_label_set_text(lbl_fault, "VESC: ---");
    lv_obj_align(lbl_fault, LV_ALIGN_BOTTOM_MID, 0, -8);
}

static void ui_update(void) {
    char buf[32];

    // Speed level with brackets for visibility
    const char* speed_str = speed_level_to_string(commanded_speed);
    snprintf(buf, sizeof(buf), "[ %s ]", speed_str);
    lv_label_set_text(lbl_speed_level, buf);

    // Speed label color
    lv_color_t speed_color;
    switch (commanded_speed) {
        case SPEED_LEVEL_OFF:    speed_color = lv_color_hex(0x888888); break;
        case SPEED_LEVEL_SLOW:   speed_color = lv_color_hex(0x44FF44); break;
        case SPEED_LEVEL_MEDIUM: speed_color = lv_color_hex(0xFFD700); break;
        case SPEED_LEVEL_FAST:   speed_color = lv_color_hex(0xFF4444); break;
        default:                 speed_color = lv_color_hex(0xFFFFFF); break;
    }
    lv_obj_set_style_text_color(lbl_speed_level, speed_color, 0);

    if (emergency_stop_active) {
        lv_label_set_text(lbl_emergency, "EMERGENCY STOP");
    } else {
        lv_label_set_text(lbl_emergency, "");
    }

    if (vesc_connected) {
        snprintf(buf, sizeof(buf), "VOLT: %.1f V", vesc_data.input_voltage);
        lv_label_set_text(lbl_voltage, buf);

        snprintf(buf, sizeof(buf), "AMPS: %.1f A", vesc_data.avg_motor_current);
        lv_label_set_text(lbl_current, buf);

        snprintf(buf, sizeof(buf), "Ah: %.2f Ah", vesc_data.amp_hours);
        lv_label_set_text(lbl_amp_hours, buf);

        snprintf(buf, sizeof(buf), "RPM: %.0f", vesc_data.rpm);
        lv_label_set_text(lbl_rpm, buf);

        snprintf(buf, sizeof(buf), "TEMP: %.1f C", vesc_data.temp_mosfet);
        lv_label_set_text(lbl_temp, buf);

        if (vesc_data.fault == VESC_FAULT_NONE) {
            lv_label_set_text(lbl_fault, "VESC: OK");
            lv_obj_set_style_text_color(lbl_fault, lv_color_hex(0x44FF44), 0);
        } else {
            snprintf(buf, sizeof(buf), "%s", vesc_fault_to_string(vesc_data.fault));
            lv_label_set_text(lbl_fault, buf);
            lv_obj_set_style_text_color(lbl_fault, lv_color_hex(0xFF4444), 0);
        }
    } else {
        lv_label_set_text(lbl_voltage, "VOLT: --.- V");
        lv_label_set_text(lbl_current, "AMPS: --.- A");
        lv_label_set_text(lbl_amp_hours, "Ah: --.-- Ah");
        lv_label_set_text(lbl_rpm, "RPM: -----");
        lv_label_set_text(lbl_temp, "TEMP: --.- C");
        lv_label_set_text(lbl_fault, "NO VESC");
        lv_obj_set_style_text_color(lbl_fault, lv_color_hex(0xFF8800), 0);
    }
}

// =============================================================================
// Motor Control
// =============================================================================

static float get_current_for_speed_level(speed_level_t level) {
    switch (level) {
        case SPEED_LEVEL_SLOW:   return CURRENT_SLOW;
        case SPEED_LEVEL_MEDIUM: return CURRENT_MEDIUM;
        case SPEED_LEVEL_FAST:   return CURRENT_FAST;
        default:                 return 0.0f;
    }
}

static void apply_motor_current(float current) {
    commanded_current = current;
    if (current > 0.1f) {
        vesc_set_current(current);
    } else {
        vesc_set_current(0.0f);
    }
}

static void enter_emergency_stop(void) {
    emergency_stop_active = true;
    commanded_speed = SPEED_LEVEL_OFF;
    apply_motor_current(0.0f);
    speed_buttons_set_all_leds(false);
    ESP_LOGW(TAG, "EMERGENCY STOP ACTIVATED");
}

static void exit_emergency_stop(speed_level_t *last_speed_level) {
    emergency_stop_active = false;
    commanded_speed = SPEED_LEVEL_OFF;
    if (last_speed_level) {
        *last_speed_level = SPEED_LEVEL_OFF;
    }
    speed_buttons_set_leds(commanded_speed);
    ESP_LOGI(TAG, "Emergency stop cleared");
}

// =============================================================================
// Tasks
// =============================================================================

static void vesc_task(void *arg) {
    (void)arg;
    TickType_t last_wake = xTaskGetTickCount();
    TickType_t last_cmd_send = 0;
    
    while (1) {
        if (vesc_get_values(&vesc_data)) {
            vesc_connected = true;
        } else {
            vesc_connected = false;
        }

        // Always send keepalive. If we only send it when "connected", a single
        // missed telemetry reply can cause us to stop keepalives and then lose comms.
        vesc_send_keepalive();

        // Continuous current command: periodically re-send the current setpoint.
        // This helps keep the VESC alive and ensures OFF/STOP is reasserted too.
        TickType_t now = xTaskGetTickCount();
        if ((now - last_cmd_send) >= pdMS_TO_TICKS(VESC_CMD_INTERVAL_MS)) {
            last_cmd_send = now;
            float cur = emergency_stop_active ? 0.0f : commanded_current;
            vesc_set_current(cur);
        }

        vTaskDelayUntil(&last_wake, pdMS_TO_TICKS(VESC_POLL_INTERVAL_MS));
    }
}

// MOMENTARY: Hold button = motor runs, release = motor stops
static void control_task(void *arg) {
    (void)arg;
    speed_level_t last_speed_level = SPEED_LEVEL_OFF;
    TickType_t all_pressed_start = 0;
    bool tracking_all_pressed = false;
    bool all_pressed_current_suppressed = false;  // True when current is suppressed during all-pressed
    TickType_t blink_last_toggle = 0;
    bool blink_state = false;
    bool prev_slow = false;
    bool prev_medium = false;
    bool prev_fast = false;

    // Fast button ramp state
    bool is_ramping_fast = false;
    TickType_t fast_ramp_start_time = 0;
    float fast_ramp_base_current = 0.0f;

    typedef enum {
        EXIT_WAIT_SLOW_PRESS = 0,
        EXIT_WAIT_SLOW_HOLD,
        EXIT_WAIT_SLOW_RELEASE,
        EXIT_WAIT_MEDIUM_PRESS,
        EXIT_WAIT_MEDIUM_HOLD,
        EXIT_WAIT_MEDIUM_RELEASE,
        EXIT_WAIT_FAST_PRESS,
        EXIT_WAIT_FAST_HOLD,
        EXIT_WAIT_FAST_RELEASE
    } emergency_exit_state_t;

    emergency_exit_state_t exit_state = EXIT_WAIT_SLOW_PRESS;
    TickType_t exit_button_hold_start = 0;
    
    while (1) {
        bool slow_pressed = false, medium_pressed = false, fast_pressed = false;
        speed_buttons_get_raw(&slow_pressed, &medium_pressed, &fast_pressed);

        bool all_pressed = slow_pressed && medium_pressed && fast_pressed;

        if (!emergency_stop_active) {
            if (all_pressed) {
                if (!tracking_all_pressed) {
                    // Just started pressing all buttons - immediately cut current
                    tracking_all_pressed = true;
                    all_pressed_current_suppressed = true;
                    all_pressed_start = xTaskGetTickCount();
                    apply_motor_current(0.0f);
                    is_ramping_fast = false;  // Cancel any ramp in progress
                    ESP_LOGI(TAG, "All buttons pressed - current suppressed");
                } else if ((xTaskGetTickCount() - all_pressed_start) >= pdMS_TO_TICKS(EMERGENCY_ENTER_HOLD_MS)) {
                    enter_emergency_stop();
                    blink_last_toggle = xTaskGetTickCount();
                    blink_state = false;
                    exit_state = EXIT_WAIT_SLOW_PRESS;
                    all_pressed_current_suppressed = false;
                }
            } else {
                // Not all pressed - restore normal operation if we were suppressing
                if (all_pressed_current_suppressed) {
                    all_pressed_current_suppressed = false;
                    // Restore current for whatever speed level is now active
                    speed_level_t current_level = speed_buttons_get_level();
                    if (current_level == SPEED_LEVEL_FAST) {
                        // Start ramping to FAST from zero
                        is_ramping_fast = true;
                        fast_ramp_start_time = xTaskGetTickCount();
                        fast_ramp_base_current = 0.0f;
                    }
                    ESP_LOGI(TAG, "All buttons released early - resuming normal");
                }
                tracking_all_pressed = false;
            }

            if (!emergency_stop_active && !all_pressed_current_suppressed) {
                speed_level_t new_speed = speed_buttons_get_level();
                
                if (new_speed != last_speed_level) {
                    if (new_speed == SPEED_LEVEL_OFF || last_speed_level == SPEED_LEVEL_OFF) {
                        ESP_LOGI(TAG, "Speed: %s", speed_level_to_string(new_speed));
                    }
                    
                    commanded_speed = new_speed;
                    speed_buttons_set_leds(commanded_speed);
                    
                    if (new_speed == SPEED_LEVEL_FAST) {
                        // Start ramping to FAST from current commanded value
                        is_ramping_fast = true;
                        fast_ramp_start_time = xTaskGetTickCount();
                        fast_ramp_base_current = commanded_current;
                        ESP_LOGI(TAG, "Starting FAST ramp from %.1fA", fast_ramp_base_current);
                    } else {
                        // Not FAST - apply current immediately and cancel any ramp
                        is_ramping_fast = false;
                        apply_motor_current(get_current_for_speed_level(new_speed));
                    }
                    
                    last_speed_level = new_speed;
                }
                
                // Handle FAST ramping - update current each iteration
                if (is_ramping_fast && commanded_speed == SPEED_LEVEL_FAST) {
                    TickType_t elapsed = xTaskGetTickCount() - fast_ramp_start_time;
                    uint32_t elapsed_ms = (uint32_t)(elapsed * portTICK_PERIOD_MS);
                    
                    if (elapsed_ms >= RAMP_TIME_FAST_MS) {
                        // Ramp complete
                        apply_motor_current(CURRENT_FAST);
                        is_ramping_fast = false;
                    } else {
                        // Calculate ramped current
                        float ramp_fraction = (float)elapsed_ms / (float)RAMP_TIME_FAST_MS;
                        float ramped_current = fast_ramp_base_current + 
                            (CURRENT_FAST - fast_ramp_base_current) * ramp_fraction;
                        apply_motor_current(ramped_current);
                    }
                }
            }
        } else {
            TickType_t now = xTaskGetTickCount();
            if ((now - blink_last_toggle) >= pdMS_TO_TICKS(500)) {
                blink_last_toggle = now;
                blink_state = !blink_state;
                speed_buttons_set_all_leds(blink_state);
            }

            if (commanded_current != 0.0f) {
                apply_motor_current(0.0f);
            }
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
void app_main(void)
{
    ESP_LOGI(TAG, "=== Death Stick Controller ===");
    ESP_LOGI(TAG, "SLOW=%.1fA, MEDIUM=%.1fA, FAST=%.1fA",
             CURRENT_SLOW, CURRENT_MEDIUM, CURRENT_FAST);

    LCD_Init();
    LVGL_Init();
    button_Init();
    speed_buttons_init();
    
    esp_err_t ret = vesc_uart_init();
    if (ret != ESP_OK) {
        ESP_LOGE(TAG, "VESC UART init failed!");
    }

    ui_create();

    xTaskCreatePinnedToCore(vesc_task, "vesc_task", 4096, NULL, 5, NULL, 0);
    xTaskCreatePinnedToCore(control_task, "control_task", 2048, NULL, 4, NULL, 0);
    xTaskCreatePinnedToCore(boot_button_task, "boot_btn_task", 2048, NULL, 3, NULL, 0);

    ESP_LOGI(TAG, "Ready - HOLD buttons for speed control");

    while (1) {
        ui_update();
        lv_timer_handler();
        vTaskDelay(pdMS_TO_TICKS(20));
    }
}

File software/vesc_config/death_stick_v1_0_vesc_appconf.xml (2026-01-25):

<?xml version="1.0" encoding="UTF-8"?>
<APPConfiguration>
    <ConfigVersion>3</ConfigVersion>
    <controller_id>84</controller_id>
    <timeout_msec>1000</timeout_msec>
    <timeout_brake_current>0</timeout_brake_current>
    <send_can_status>4</send_can_status>
    <send_can_status_rate_hz>50</send_can_status_rate_hz>
    <can_baud_rate>2</can_baud_rate>
    <pairing_done>0</pairing_done>
    <permanent_uart_enabled>1</permanent_uart_enabled>
    <shutdown_mode>7</shutdown_mode>
    <can_mode>0</can_mode>
    <uavcan_esc_index>0</uavcan_esc_index>
    <uavcan_raw_mode>0</uavcan_raw_mode>
    <app_to_use>3</app_to_use>
    <app_ppm_conf.ctrl_type>0</app_ppm_conf.ctrl_type>
    <app_ppm_conf.pid_max_erpm>15000</app_ppm_conf.pid_max_erpm>
    <app_ppm_conf.hyst>0.15</app_ppm_conf.hyst>
    <app_ppm_conf.pulse_start>1</app_ppm_conf.pulse_start>
    <app_ppm_conf.pulse_end>2</app_ppm_conf.pulse_end>
    <app_ppm_conf.pulse_center>1.5</app_ppm_conf.pulse_center>
    <app_ppm_conf.median_filter>1</app_ppm_conf.median_filter>
    <app_ppm_conf.safe_start>1</app_ppm_conf.safe_start>
    <app_ppm_conf.throttle_exp>0</app_ppm_conf.throttle_exp>
    <app_ppm_conf.throttle_exp_brake>0</app_ppm_conf.throttle_exp_brake>
    <app_ppm_conf.throttle_exp_mode>2</app_ppm_conf.throttle_exp_mode>
    <app_ppm_conf.ramp_time_pos>0.4</app_ppm_conf.ramp_time_pos>
    <app_ppm_conf.ramp_time_neg>0.2</app_ppm_conf.ramp_time_neg>
    <app_ppm_conf.multi_esc>1</app_ppm_conf.multi_esc>
    <app_ppm_conf.tc>0</app_ppm_conf.tc>
    <app_ppm_conf.tc_max_diff>3000</app_ppm_conf.tc_max_diff>
    <app_ppm_conf.max_erpm_for_dir>4000</app_ppm_conf.max_erpm_for_dir>
    <app_ppm_conf.smart_rev_max_duty>0.07</app_ppm_conf.smart_rev_max_duty>
    <app_ppm_conf.smart_rev_ramp_time>3</app_ppm_conf.smart_rev_ramp_time>
    <app_adc_conf.ctrl_type>0</app_adc_conf.ctrl_type>
    <app_adc_conf.hyst>0.15</app_adc_conf.hyst>
    <app_adc_conf.voltage_start>0.9</app_adc_conf.voltage_start>
    <app_adc_conf.voltage_end>3</app_adc_conf.voltage_end>
    <app_adc_conf.voltage_center>2</app_adc_conf.voltage_center>
    <app_adc_conf.voltage2_start>0.9</app_adc_conf.voltage2_start>
    <app_adc_conf.voltage2_end>3</app_adc_conf.voltage2_end>
    <app_adc_conf.use_filter>1</app_adc_conf.use_filter>
    <app_adc_conf.safe_start>1</app_adc_conf.safe_start>
    <app_adc_conf.cc_button_inverted>0</app_adc_conf.cc_button_inverted>
    <app_adc_conf.rev_button_inverted>0</app_adc_conf.rev_button_inverted>
    <app_adc_conf.voltage_inverted>0</app_adc_conf.voltage_inverted>
    <app_adc_conf.voltage2_inverted>0</app_adc_conf.voltage2_inverted>
    <app_adc_conf.throttle_exp>0</app_adc_conf.throttle_exp>
    <app_adc_conf.throttle_exp_brake>0</app_adc_conf.throttle_exp_brake>
    <app_adc_conf.throttle_exp_mode>2</app_adc_conf.throttle_exp_mode>
    <app_adc_conf.ramp_time_pos>0.3</app_adc_conf.ramp_time_pos>
    <app_adc_conf.ramp_time_neg>0.1</app_adc_conf.ramp_time_neg>
    <app_adc_conf.multi_esc>1</app_adc_conf.multi_esc>
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

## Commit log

2025-06-11 Added parts ordered
    [parts.csv]
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2025-06-21 More parts ordewred
    [parts.csv]
2025-06-22 more parts and part docs added
    [parts.csv]
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2025-07-07 Flipsky order
    [parts.csv]
2025-07-20 Added BMS spec. Added new cable gland and pics
    [parts.csv]
2025-08-03 Added first version of the CAd part cell spacers. Used step file.
    [Part Studio 1 - cell_spacer.step]
2025-08-03 Updated cell spacer made the ends better fit the cell dimensions.
    [Part Studio 1 - cell_spacer.step]
2025-08-03 Better fit cell ends again.
    [Part Studio 1 - cell_spacer.step]
2025-08-03 new cell spacer better fit design. Added potential buttons for control
    [Part Studio 1 - cell_spacer.3mf]
2025-08-16 Ordered polycarbonate for ends.
    [parts.csv]
2025-08-17 Latest cell spacer and first tube end CAD models added
    [Part Studio 1 - cell_spacer.step, Part Studio 1 - end_tube_cap.step]
2025-08-17 better fit cell spacer
    [Part Studio 1 - cell_spacer.step]
2025-08-17 Updated analysis. Added top end tube cap CAD part.
    [Part Studio 1 - cell_spacer.3mf, Part Studio 1 - top_tube_end_cap.step, parts.csv]
2025-08-17 electircal tap and sponge and push buttons orders added. Part list updated.
    [parts.csv]
2025-08-23 Larger top end so we can fit the cells in the top end and then oring seal up the tube.
    [Part Studio 1 - top_tube_end_cap.step]
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2025-08-31 Added buttons to wiring diagram. Added order for the correct sized Orings.
2025-08-31 Added lareger oring to patrs
    [parts.csv]
2025-08-31 Added parts for holding motor and BMS
    [Death Stick Crotch Blender parts - Part27^Assembly 1.step, Death Stick Crotch Blender parts - Part28^Assembly 1.step, Death Stick Crotch Blender parts - Part29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]
2025-09-13 Bought touch screen and DCDC voltage regualtor for controls.
    [parts.csv]
2025-09-14 Xt90 connectors and power 12awg cable
    [parts.csv]
2025-09-14 New BMS holder cell end CAD
    [Part Studio 1 - cell_spacer_pos_end.step]
2025-09-14 mirrored mototr tube connection
    [Death Stick Crotch Blender parts - Part27^Assembly 1.step]
2025-10-04 Added new CAD parts to hold the motor
    [Death Stick Crotch Blender parts - Part28^Assembly 1.step, motor_holders.3mf]
2025-10-04 build podman container to build esp lcd examples in. Added the examples and the esp32S3 hardweare docs
2025-10-04 added example touch screen project
    [partitions.csv]
2025-10-04 move to v5.1.4 as the esp-idf docs states for our demo board ESP32-S3-LCD-1.47B
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2025-10-11 Copied the 01_factory example from exampels as this built and run and displayed on the screen.
    [partitions.csv]
2025-10-12 Added CAD total assembly to tthe project from oneshape export
    [Death Stick Assembly 1.step]
2025-10-12 added comms cable to parts
    [parts.csv]
2025-10-18 Added CAD BMS end spacer
    [Part Studio 1 - cell_spacer_pos_end.step]
2025-10-18 Fixed cell balancing wiring diagram
2025-11-02 Addef 160A fuse to the parts. We will install this on the negativev endf of the battery
    [parts.csv]
2025-11-09 doubled threead insert depth so we can double the inserts up to prevent them pulling out again
    [Part Studio 1 - end_tube_cap.step]
2025-11-09 increased inner diameter to match 56 mm so we can smoothly slide in the battery cells with no lip on this top piece.
    [Part Studio 1 - top_tube_end_cap.step]
2025-11-15 added cell spacer negative end
    [Part Studio 1 - cell_spacer_neg_end.step]
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2025-12-01 Added workign example project and removed previous test examples. Minimal project buidls and runs and dispaly images with button press chaing a square color.
    [partitions.csv]
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2025-12-02 Uart settgins required to communicate wit the flipsky motor.
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2025-12-09 add the button holder CAD step file
    [Part Studio 1 - button_holder.step]
2025-12-09 Added carbon fiber tubign to parts tables list
    [parts.csv]
2025-12-10 udpate the button holder to add notch to hold the hose clamps in place
    [Part Studio 1 - button_holder.step]
2025-12-13 CAD of button holder added and printed
    [Part Studio 1 - button_holder.step]
2025-12-13 Updated parts list in CSV with new components including prototyping board, NPN transistors, and resistors. Added a new PDF for Jaycar NPN transistors PCB development board resistors. Modified wiring 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
    [parts.csv]
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2025-12-19 Enhanced the wiring diagram for the death stick project by adding new components, including resistors and transistors, and improving the layout for better clarity and accuracy. Updated connection poi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
    Added death stick vesc config form the vesc tool after first configuraiotn of the app and motor vesc.
    [death_stick_v1_0_vesc_appconf.xml, death_stick_v1_0_vesc_mcconf.xml]
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2026-01-03 Add motor mount CAD files and update speed button LED control logic. Fixed bug in wirign diagram showing incorrect NPNO transistor pin outs
    - Added new STEP files for motor mount components: motor_mount_top.step and motor_mount_bottom.step.
    - Updated Speed_Buttons module to implement active low LED control, enhancing GPIO initialization and LED state management for speed indicators.
    - Defined LED drive levels for better clarity in the code.
    [Part Studio 1 - motor_mount_bottom.step, Part Studio 1 - motor_mount_top.step]
2026-01-03 swapped motor direction
    [death_stick_v1_0_vesc_mcconf.xml]
2026-01-17 Updated motor current settings for low and medium power modes. Added periodic command reassertion for VESC to prevent timeout issues. Changed certain variables to volatile to ensure proper operation 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
    [main.c]
2026-01-24 increase thickness to prevent breaking
    [Part Studio 1 - button_holder.step]
2026-01-24 slight cad fix to fillet
    [Part Studio 1 - button_holder.step]
2026-01-24 adjusted angle of motor holder. Now sits another 35 degrees lower so you can hold the stick further forwards and have the motor further behind you
    [Part Studio 1 - motor_mount_bottom.step, Part Studio 1 - motor_mount_top.step]
2026-01-25 top end cap covering
    [Part Studio 1 - top_end_cap.step]
2026-01-25 Added to README and stick controller logic for button controls and emergency stop functionality.
    - Added detailed button control instructions to README, including speed settings and emergency stop procedures.
    - Implemented ramping behavior for the FAST button in the stick controller, allowing gradual acceleration.
    - Updated emergency stop logic to ensure exclusive button presses are handled correctly during exit sequences.
    [main.c]
2026-01-25 reduced min vesc voltage l_battery_cut_start is now 31V and l_battery_cut_end is 28,5V this still gives us 2.85V per cell before cutting off power. THe NMC cells are fine to 2.7V each.
    [death_stick_v1_0_vesc_appconf.xml, death_stick_v1_0_vesc_mcconf.xml]
